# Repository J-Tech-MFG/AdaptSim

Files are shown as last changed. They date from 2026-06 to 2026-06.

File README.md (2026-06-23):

# AdaptSim

### A modular DIY direct drive sim racing ecosystem built from accessible parts, custom CAD, and open-source hardware.

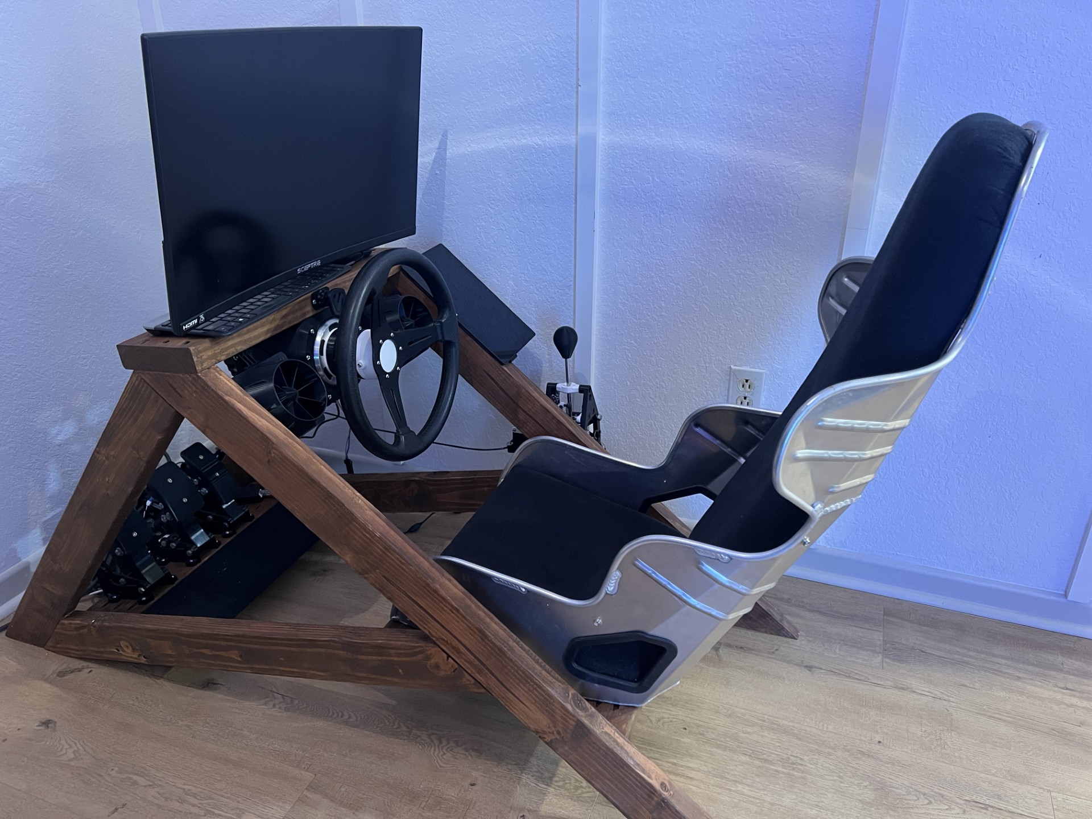
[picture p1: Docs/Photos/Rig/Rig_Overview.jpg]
Rig Overview


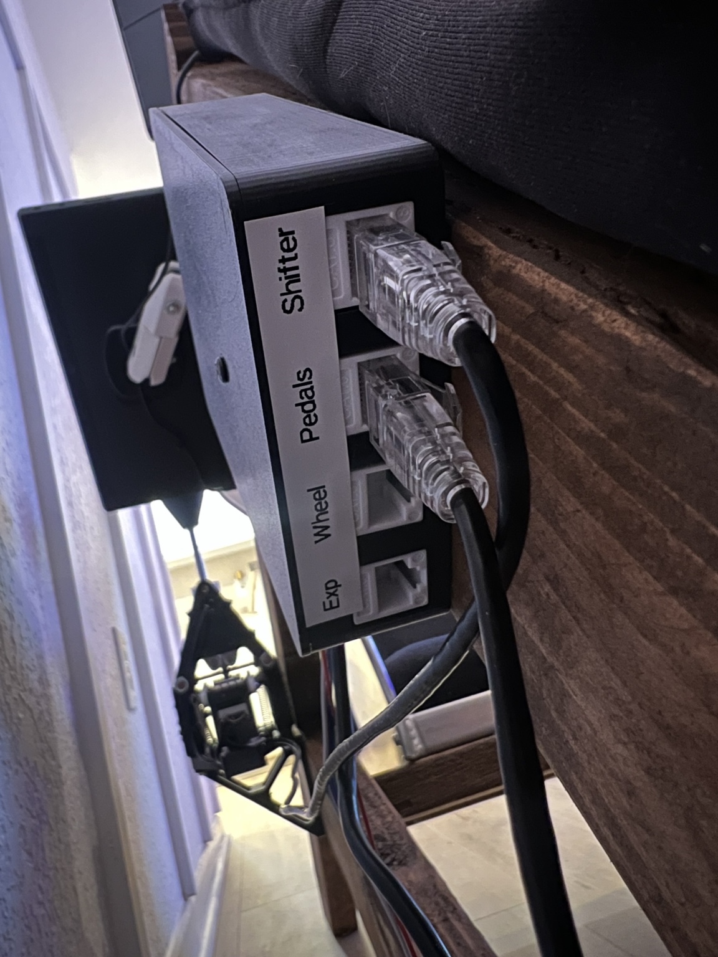
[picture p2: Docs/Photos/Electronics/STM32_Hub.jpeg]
RJ45 Controller








---

# Overview

AdaptSim is a DIY sim racing project centered around a custom STM32 controller, direct drive force feedback wheel, load-cell pedals, H-pattern shifter, pedal rumble system, and SimHub-powered wind simulation.

The goal of this project was simple:

> Build a high-performance simulator using affordable components, recycled hardware, 3D printed parts, and custom CAD rather than expensive proprietary equipment.

Everything was designed around adaptability. The included STEP files are intended to be modified and customized to fit whatever hardware you have available.

---

# Design Philosophy

AdaptSim is **not a kit**.

The parts used in this build were largely chosen based on what I already had available. Because of that, exact hardware counts and dimensions may differ from your build.

Instead of requiring exact replicas, the provided STEP files allow builders to:

- Modify dimensions
- Change mounting patterns
- Use different hardware
- Adapt electronics layouts
- Customize ergonomics

If you have different bearings, springs, fasteners, sensors, or materials, modify the CAD and make it your own.

---

# Features

## Direct Drive Wheel

- 350W Hoverboard Motor
- 36V Rated Motor
- 15 Pole Pair Configuration
- MT6701 Magnetic Encoder
- FFBeast Firmware
- STM32-based controller
- SimHub Compatible

## Load Cell Pedals

- Custom modified pedal design
- 200kg load cell brake
- HX711 load cell amplifier
- KY-035 analog hall sensors
- Magnetic throttle and clutch sensing
- Adjustable geometry
- Adjustable pedal spacing

## H-Pattern Shifter

- Fully custom CAD design
- Spring centering mechanism
- Limit switch gear detection
- Serviceable design

## Modular Electronics

- STM32F407VET6 controller
- RJ45 modular wiring system
- Dedicated wheel port
- Dedicated pedal port
- Dedicated shifter port
- Expansion port for future accessories

## SimHub Integration

- Dual pedal rumble motors
- Speed-based wind simulation
- Drafting effects
- Left/right airflow effects

---

# Rig Overview

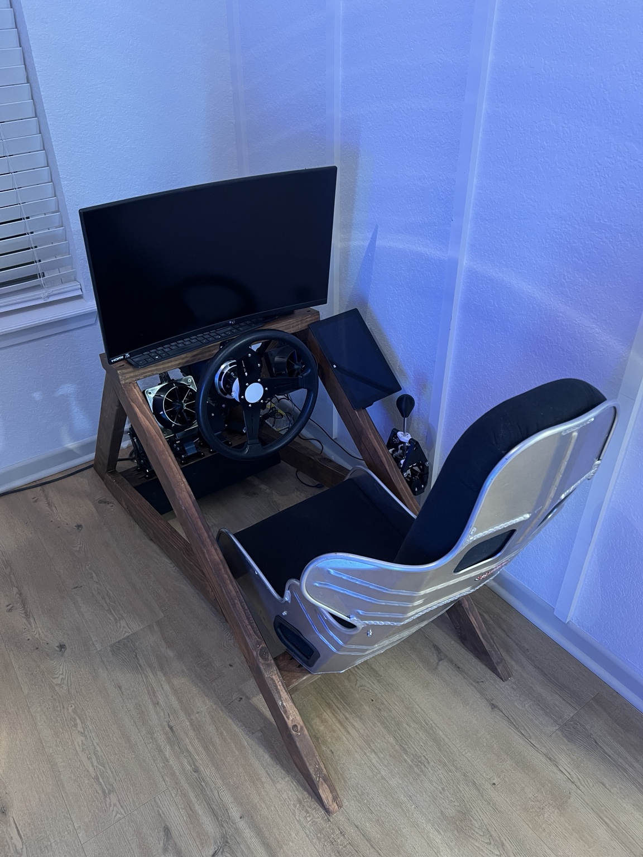
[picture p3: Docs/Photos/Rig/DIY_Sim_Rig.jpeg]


The simulator frame is a simple wood construction designed around affordability and rigidity.

Major systems include:

- Direct drive wheel
- Load-cell pedals
- H-pattern shifter
- SimHub wind simulator
- Pedal rumble feedback
- STM32 controller system

---

# Direct Drive Wheel

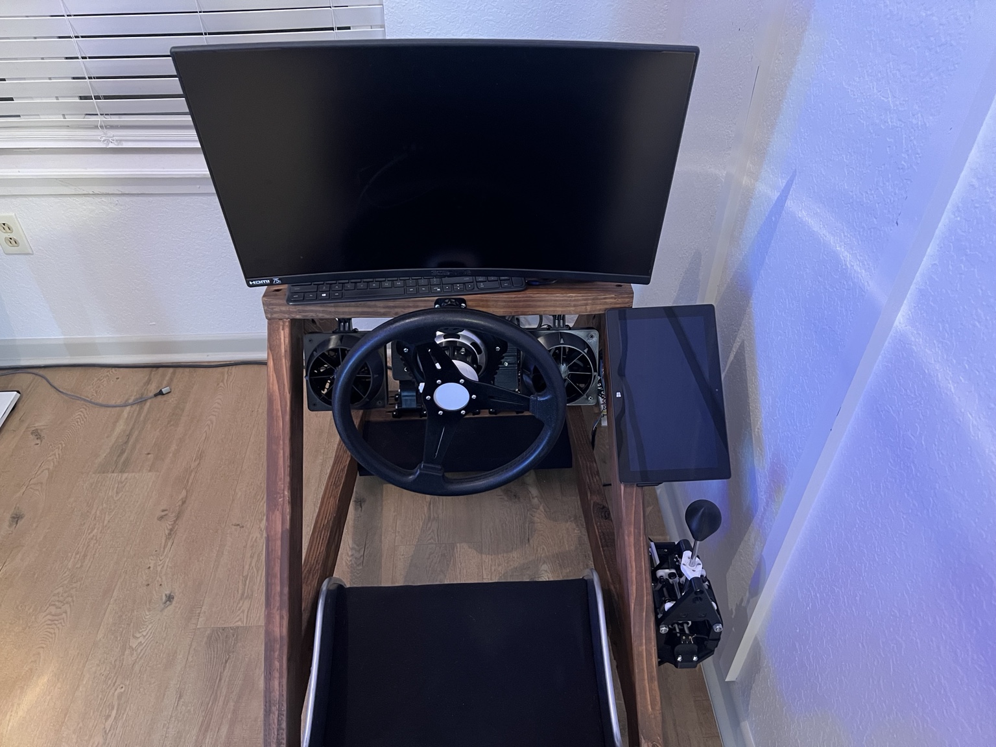
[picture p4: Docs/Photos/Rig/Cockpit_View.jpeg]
Wheel


## Hardware

| Component | Description |
|---|---|
| Motor | 6.5" Hoverboard Motor |
| Rated Power | 350W |
| Voltage | 36V |
| Pole Pairs | 15 |
| Encoder | MT6701 Magnetic Encoder |
| Controller | FFBeast |
| Power Supply | 24V 10A |

---

# Pedals

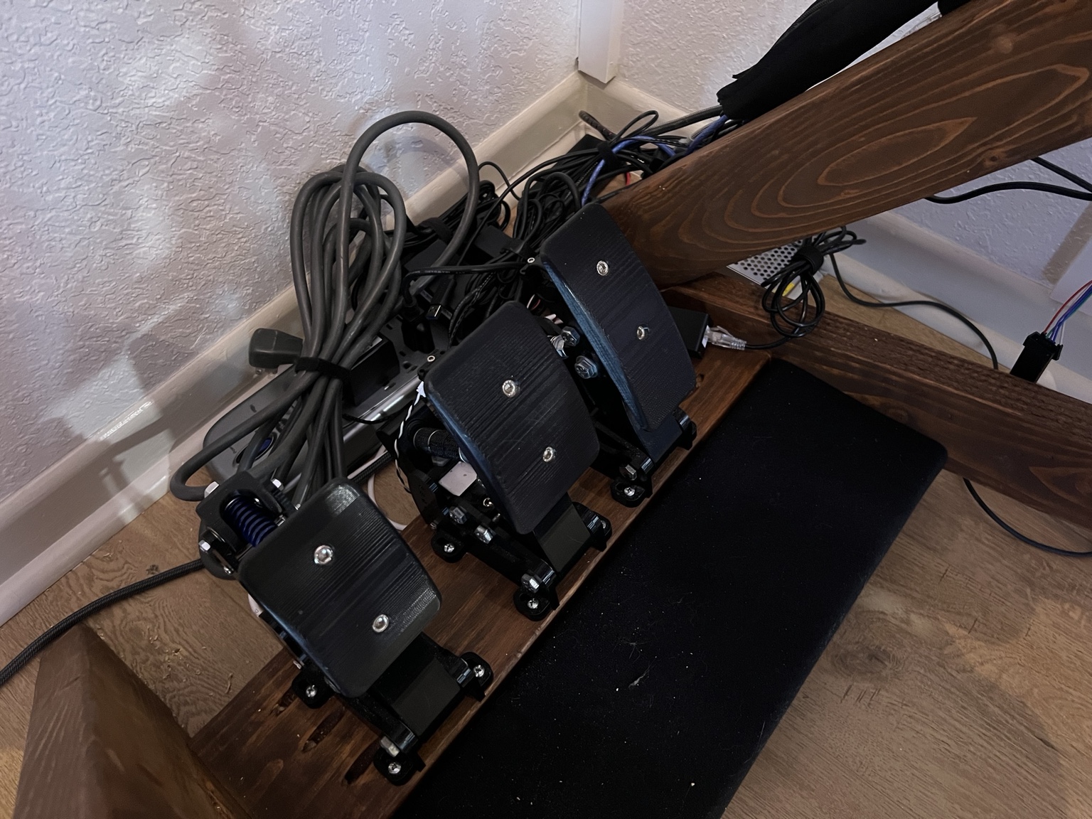
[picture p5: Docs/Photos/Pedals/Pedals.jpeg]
Pedals


## Sensors

### Throttle

- KY-035 Analog Hall Sensor
- 8mm x 3mm Neodymium Magnet

### Clutch

- KY-035 Analog Hall Sensor
- 8mm x 3mm Neodymium Magnet

### Brake

- 200kg Load Cell
- HX711 Amplifier Module

## Construction

- PETG Printed Components
- 608 Bearings
- M5 Threaded Rod
- M6 Hardware
- 5/16" Hardware

---

# H-Pattern Shifter

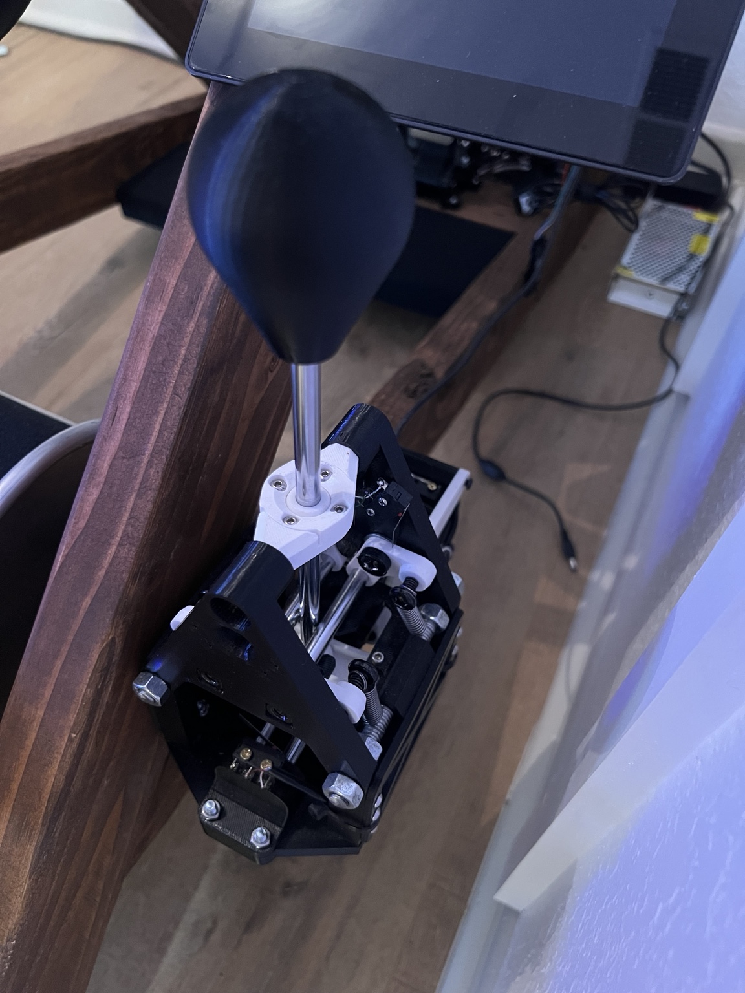
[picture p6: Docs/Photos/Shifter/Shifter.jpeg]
Shifter


The shifter was designed from scratch in CAD and developed around readily available hardware and linear motion components.

## Hardware

| Qty | Component |
|---|---|
| 4 | KW11-3Z-C Limit Switches |
| Assorted | 8mm Linear Rod |
| 4 | 8mm Linear Bearings |
| Assorted | M3 Hardware |
| Assorted | M4 Hardware |
| Assorted | M6 Threaded Rod |
| Assorted | M8 Threaded Rod |
| Assorted | 5/16" Threaded Rod |
| Assorted | Heat Set Inserts |
| Assorted | Extension Springs |

---

# Electronics Architecture

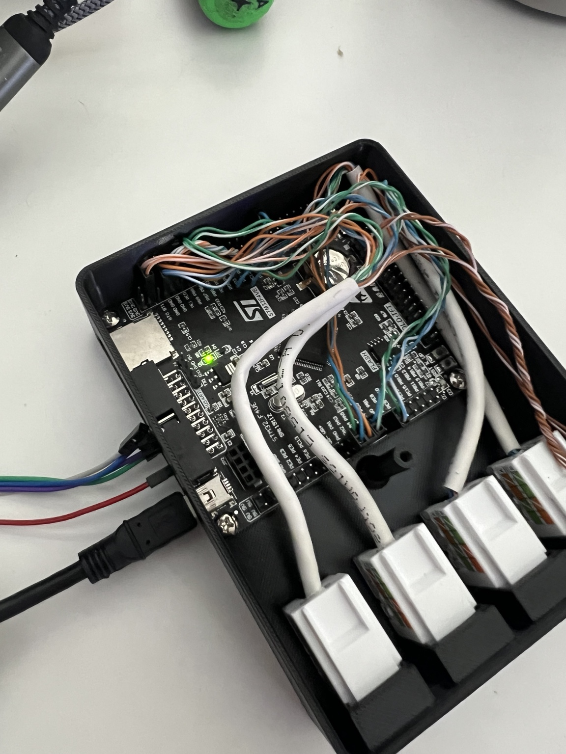
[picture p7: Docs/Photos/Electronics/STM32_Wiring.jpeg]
STM32 Wiring


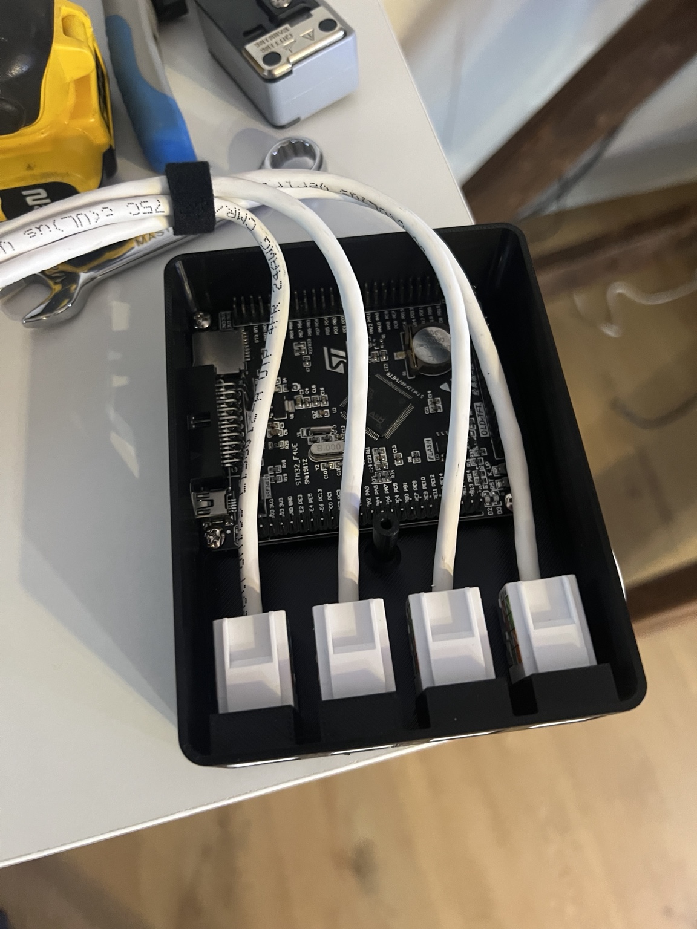
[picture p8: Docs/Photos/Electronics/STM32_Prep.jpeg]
STM32 Assembly


The entire simulator is built around a STM32F407VET6 microcontroller and a modular RJ45 wiring system.

## Ports

| Port | Function |
|---|---|
| Wheel | Wheel Controls |
| Pedals | Pedal Sensors |
| Shifter | Gear Detection |
| Expansion | Future Accessories |

Using RJ45 cabling allows easy serviceability and future expansion without rewiring the entire simulator.

---

# Pedal Rumble System

## Hardware

| Component | Description |
|---|---|
| Controller | Arduino Pro Micro |
| Driver | DRV8833 Dual H-Bridge |
| Motors | Xbox Controller Rumble Motors (2x) |
| Power Supply | 5V 2A USB Supply |

## SimHub Effects

- Wheel Slip
- ABS Feedback
- Wheel Lock
- Engine Vibration
- Road Impacts

---

# Wind Simulation

## Hardware

| Component | Description |
|---|---|
| Controller | Arduino Pro Micro |
| Fans | Thermalright TL-C12C PWM |
| Quantity | 2 |
| Voltage | 12V |
| Speed | 1550 RPM |
| Power Supply | 12V 1A |

## SimHub Effects

- Vehicle Speed
- Airflow Curving
- Drafting Effects

---

# CAD Files

The repository includes STEP files for:

- Pedals
- H-Pattern Shifter
- STM32 Controller Enclosure

Only STEP files are provided.

This allows builders to import and modify the designs in virtually any CAD software.

---

## Opening the Project

This repository intentionally omits some STM32CubeIDE workspace metadata files.

To open the project:

1. Open `AdaptSim_STM32.ioc` in STM32CubeMX
2. Generate code
3. Open the generated project in STM32CubeIDE
4. Build and flash

All required source code is included in this repository.

---

## SimHub Integration

This project includes optional SimHub-powered accessories:

- Pedal rumble feedback using Xbox controller rumble motors
- Wind simulation using dual PWM fans

Both systems use Arduino Pro Micro boards running firmware generated directly by SimHub.

No custom Arduino firmware is required.

See the Docs folder for setup instructions and wiring information.

---

# Credits

## Pedal Design Inspiration

This project began with the excellent pedal design by:

https://www.printables.com/model/1394243-sim-racing-pedals-with-load-cell-v2

The pedal assemblies in this repository are heavily modified versions adapted to fit this simulator's specific requirements.

---

## Shifter Inspiration

The shifter was inspired by:

https://dazprojects.com/products/h-shifter-3d-models

No files, models, or CAD data were purchased, downloaded, or reused. The design included here was created independently from scratch.

---

## Wind Simulator Credits

The wind simulator used in this project is based on the excellent design created by:

https://makerworld.com/en/models/1561872-3d-printed-wind-simulator-kit-for-sim-racing

I used their printed fan mounts and wind simulation design directly in my build because it is a well-designed and easy-to-implement solution.

The only significant modification was the electronics enclosure and controller implementation. Instead of the original Arduino Uno based design, this project uses an Arduino Pro Micro integrated into the overall AdaptSim electronics ecosystem.

The original creator's files are not included in this repository. If you would like to build the wind simulator, please visit their MakerWorld page and download the files directly from the original source.

Thank you to the original designer for making the project available to the community.

---

# License

This project is released under the MIT License.

Build it. Modify it. Improve it. Share it.

🏁

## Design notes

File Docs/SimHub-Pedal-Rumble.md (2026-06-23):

# Pedal Rumble System

## Hardware

- Arduino Pro Micro
- DRV8833 Dual H-Bridge Driver
- 2x Xbox Controller Rumble Motors
- 5V 2A USB Power Supply

## SimHub Configuration

Device Type:
- Dual Motor Output

Outputs:
- Motor 1 = Brake
- Motor 2 = Throttle

## Notes

Firmware is generated and uploaded directly by SimHub.
No custom Arduino code is required.

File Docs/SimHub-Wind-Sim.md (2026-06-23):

# Wind Simulation System

## Hardware

- Arduino Pro Micro
- 2x Thermalright TL-C12C PWM Fans
- 12V 1A Power Supply

## SimHub Configuration

Device Type:
- PWM Fan Controller

Pins:
- Fan 1 PWM = D9
- Fan 2 PWM = D10

## Features

- Speed-based airflow
- Left/right airflow effects
- Drafting effects

## Credits

Fan mounting concept based on:

https://makerworld.com/en/models/1561872-3d-printed-wind-simulator-kit-for-sim-racing

The original fan files are not included in this repository.

## Notes

Firmware is generated and uploaded directly by SimHub.
No custom Arduino code is required.

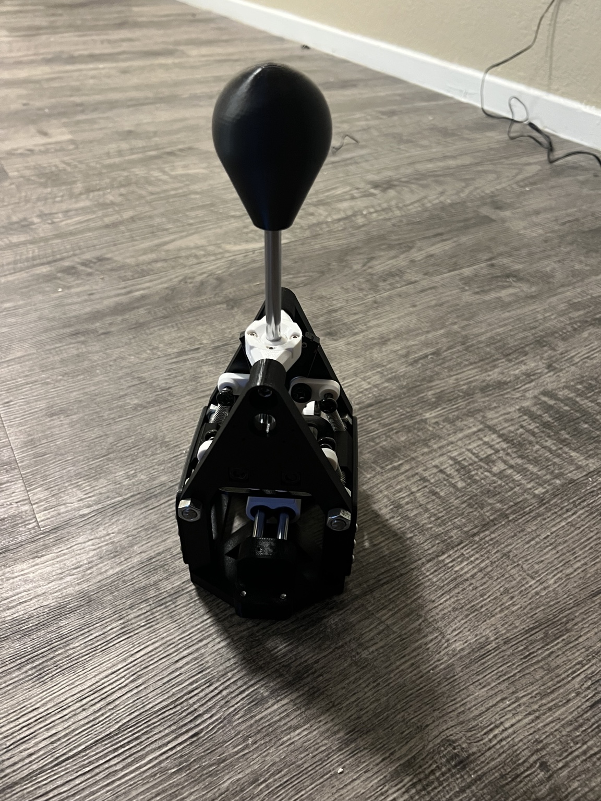
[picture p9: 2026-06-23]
Docs/Photos/Shifter/Shifter_Rear_View.jpeg

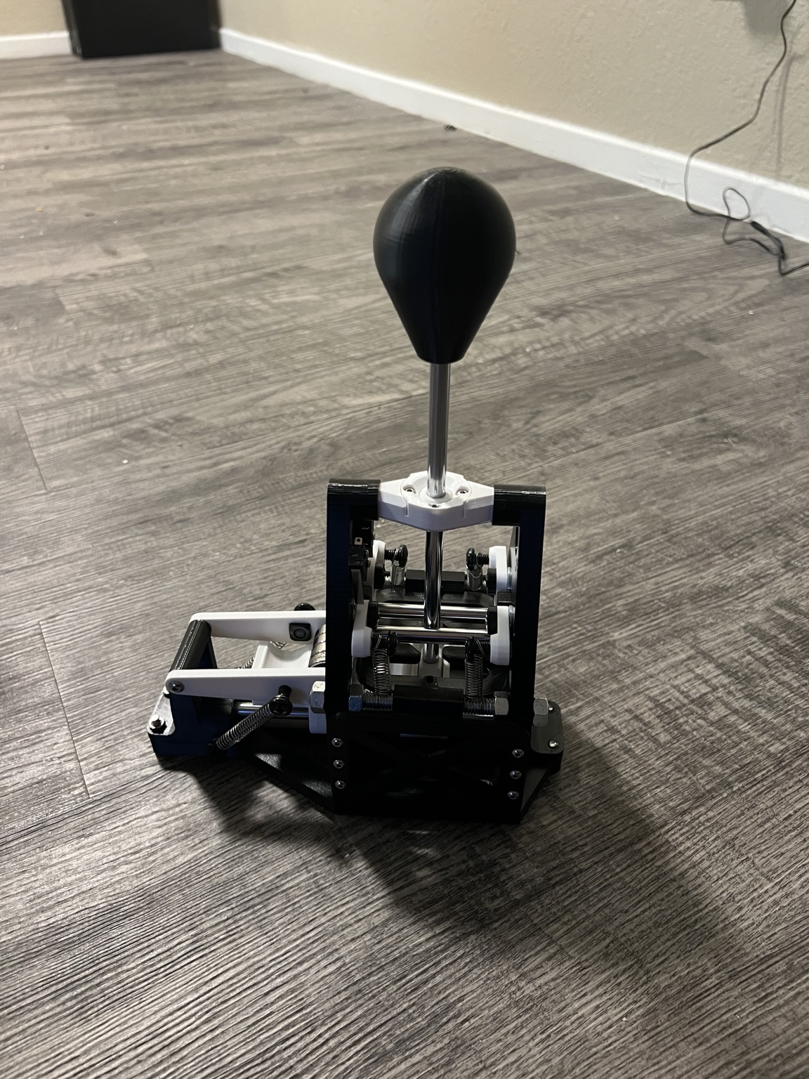
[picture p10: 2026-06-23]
Docs/Photos/Shifter/Shifter_Side_View.jpeg

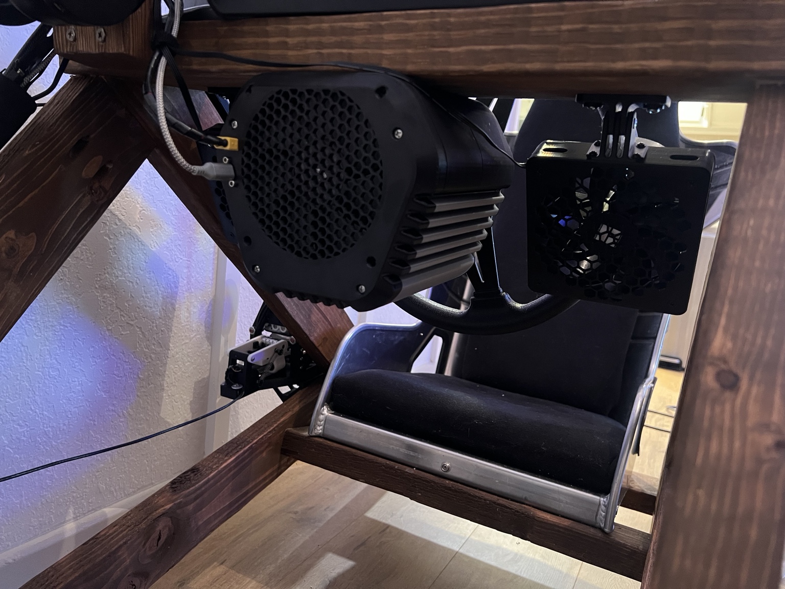
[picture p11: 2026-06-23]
Docs/Photos/Wheel/Wheel_and_Wind.jpeg

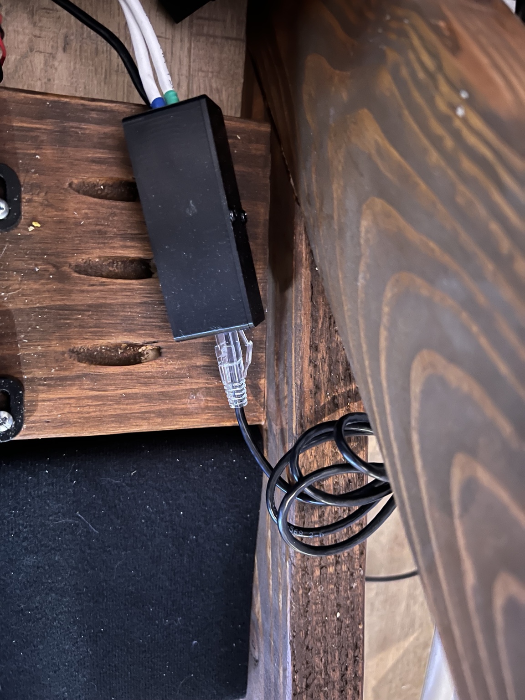
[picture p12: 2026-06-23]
Docs/Photos/Pedals/Pedal_Module.jpeg

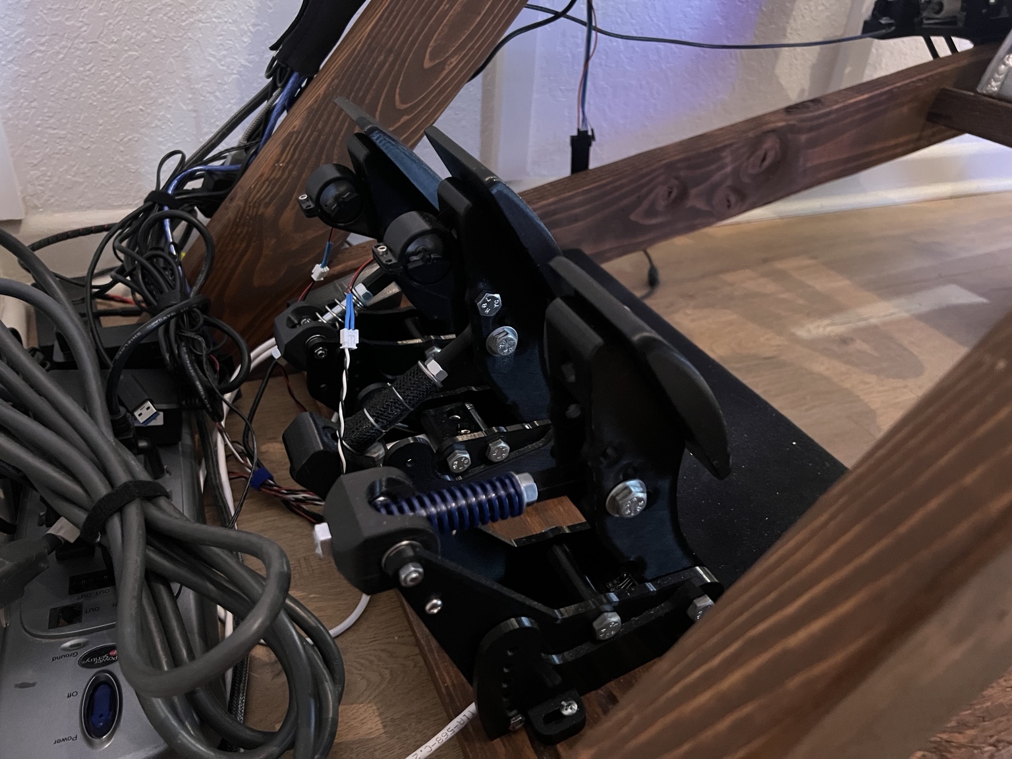
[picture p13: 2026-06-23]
Docs/Photos/Pedals/Pedals_Side_View.jpeg

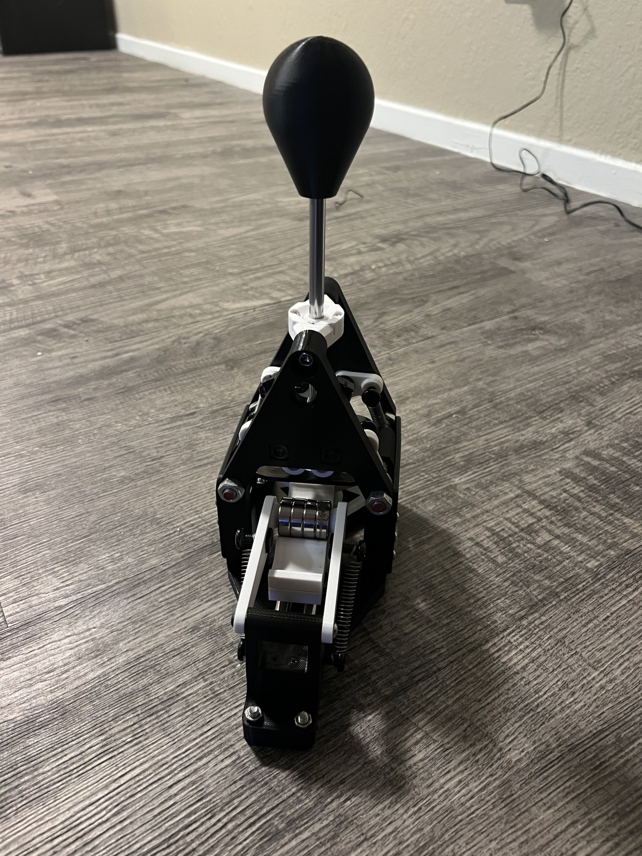
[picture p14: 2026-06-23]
Docs/Photos/Shifter/Shifter_Front_View.jpeg

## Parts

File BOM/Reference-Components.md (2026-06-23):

# Reference Components

Work in progress.

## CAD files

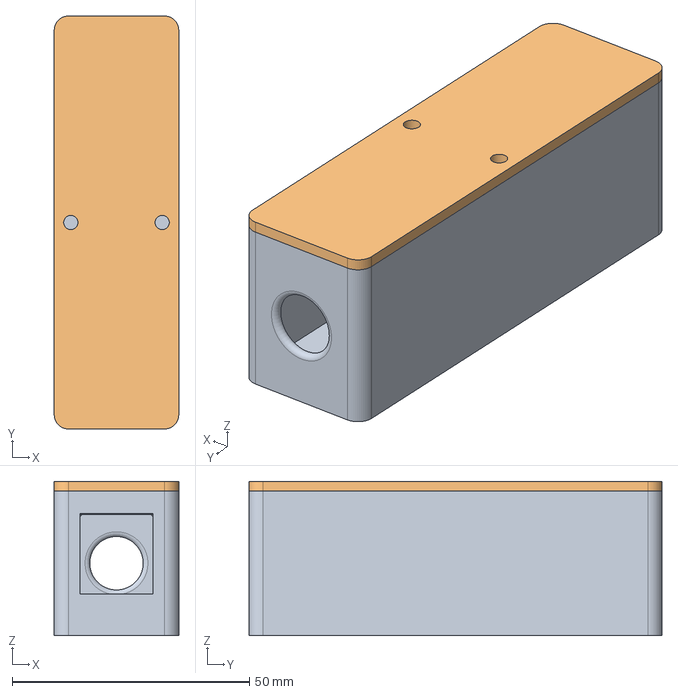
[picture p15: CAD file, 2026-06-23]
CAD/Pedals/Sim_Pedal_Electronic_Enclosure.step
26.3 x 87.0 x 32.5 mm

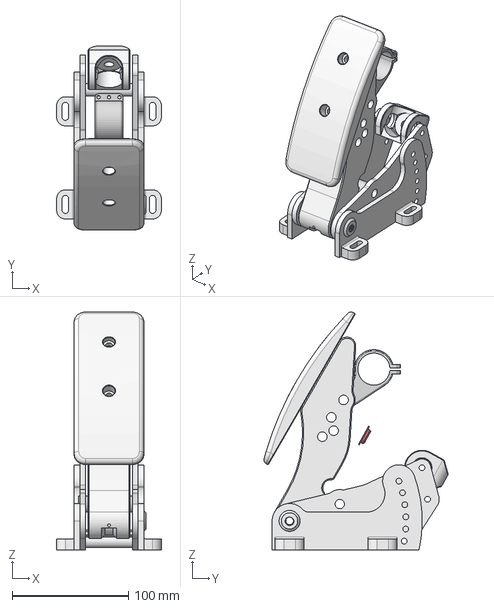
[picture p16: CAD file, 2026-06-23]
CAD/Pedals/FreeSim-Pedal-Throttle.step
90.0 x 158.3 x 204.5 mm
Pedal_Arm

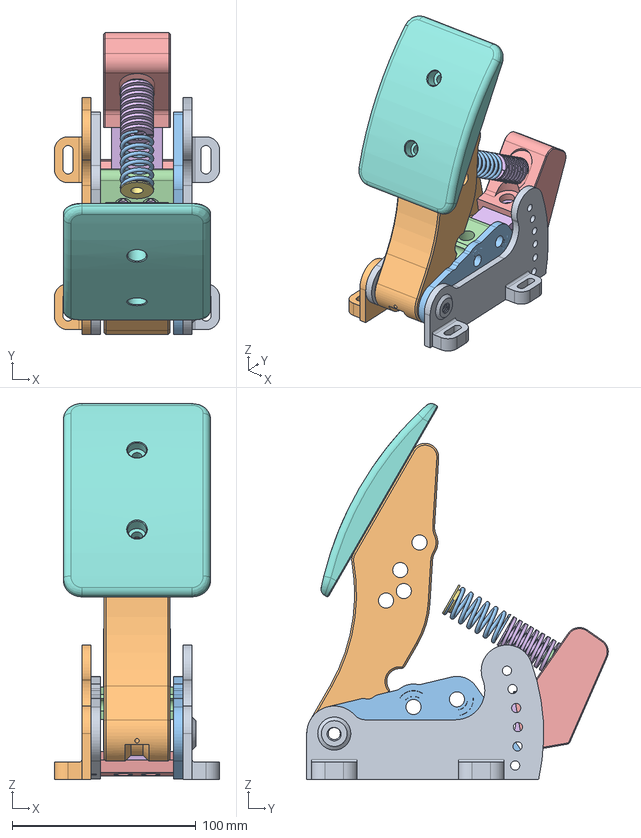
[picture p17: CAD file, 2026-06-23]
CAD/Pedals/FreeSim-Pedal-Brake.step
90.0 x 164.1 x 204.6 mm
Side_Mount_Left
Pedal_Arm (1)

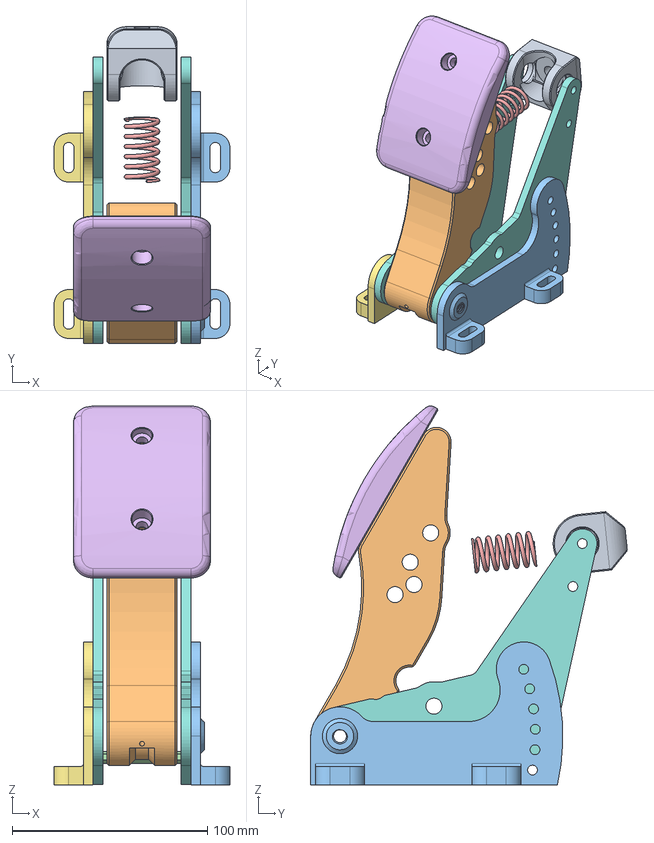
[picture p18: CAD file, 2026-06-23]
CAD/Pedals/FreeSim-Pedal-Clutch.step
90.0 x 162.0 x 193.9 mm
Pedal_Arm (2)
Side_Mount_Left
KY-035_Analog_Hall_Mount

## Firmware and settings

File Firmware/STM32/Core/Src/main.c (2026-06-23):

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
/* Includes ------------------------------------------------------------------*/
#include "main.h"
#include "usb_device.h"

/* USER CODE BEGIN Includes */
#include <stdio.h>
#include <string.h>
#include "usbd_hid.h"
/* USER CODE END Includes */

ADC_HandleTypeDef hadc1;

void SystemClock_Config(void);
static void MX_GPIO_Init(void);
static void MX_ADC1_Init(void);
/* USER CODE BEGIN 0 */
extern USBD_HandleTypeDef hUsbDeviceFS;

typedef struct __attribute__((packed))
{
  uint16_t throttle;
  uint16_t brake;
  uint16_t clutch;
  uint32_t buttons;
} SimHID_Report_t;

#define THROTTLE_MIN 2190
#define THROTTLE_MAX 3150

#define CLUTCH_MIN   2180
#define CLUTCH_MAX   1494

#define BRAKE_MIN    22000
#define BRAKE_MAX    600000

static int32_t clamp_i32(int32_t value, int32_t min, int32_t max)
{
  if (value < min) return min;
  if (value > max) return max;
  return value;
}

static uint32_t read_adc_channel(uint32_t channel)
{
  ADC_ChannelConfTypeDef sConfig = {0};

  sConfig.Channel = channel;
  sConfig.Rank = 1;
  sConfig.SamplingTime = ADC_SAMPLETIME_15CYCLES;

  HAL_ADC_ConfigChannel(&hadc1, &sConfig);
  HAL_ADC_Start(&hadc1);
  HAL_ADC_PollForConversion(&hadc1, 10);
  uint32_t value = HAL_ADC_GetValue(&hadc1);
  HAL_ADC_Stop(&hadc1);

  return value;
}

static void hx711_delay(void)
{
  for (volatile int i = 0; i < 80; i++);
}

static int32_t hx711_read(void)
{
  int timeout = 1000000;

  while (HAL_GPIO_ReadPin(GPIOB, GPIO_PIN_0) == GPIO_PIN_SET)
  {
    if (--timeout == 0)
      return 0;
  }

  int32_t count = 0;

  for (uint8_t i = 0; i < 24; i++)
  {
    HAL_GPIO_WritePin(GPIOB, GPIO_PIN_1, GPIO_PIN_SET);
    hx711_delay();

    count <<= 1;
    if (HAL_GPIO_ReadPin(GPIOB, GPIO_PIN_0) == GPIO_PIN_SET)
      count++;

    HAL_GPIO_WritePin(GPIOB, GPIO_PIN_1, GPIO_PIN_RESET);
    hx711_delay();
  }

  // Gain 128, Channel A
  HAL_GPIO_WritePin(GPIOB, GPIO_PIN_1, GPIO_PIN_SET);
  hx711_delay();

  HAL_GPIO_WritePin(GPIOB, GPIO_PIN_1, GPIO_PIN_RESET);
  hx711_delay();

  if (count & 0x800000)
    count |= 0xFF000000;

  return count;
}

/* USER CODE END 0 */

/**
  * @brief  The application entry point.
  * @retval int
  */
int main(void)
{

  /* MCU Configuration--------------------------------------------------------*/

  /* Reset of all peripherals, Initializes the Flash interface and the Systick. */
  HAL_Init();

  /* Configure the system clock */
  SystemClock_Config();

  /* Initialize all configured peripherals */
  MX_GPIO_Init();
  MX_USB_DEVICE_Init();
  MX_ADC1_Init();
  /* Infinite loop */
  /* USER CODE BEGIN WHILE */
  while (1)
  {
    /* USER CODE END WHILE */

    /* USER CODE BEGIN 3 */

	  uint32_t clutchRaw   = read_adc_channel(ADC_CHANNEL_4);
	  uint32_t throttleRaw = read_adc_channel(ADC_CHANNEL_5);
	  static int32_t brakeRaw = BRAKE_MIN;
	  static uint32_t lastBrakeRead = 0;

	  if (HAL_GetTick() - lastBrakeRead >= 80)
	  {
	    int32_t newBrakeRaw = hx711_read();

	    if (newBrakeRaw != 0)
	    {
	      brakeRaw = newBrakeRaw;
	    }

	    lastBrakeRead = HAL_GetTick();
	  }

	  uint16_t throttleAxis =
	      (uint16_t)clamp_i32(
	          ((int32_t)throttleRaw - THROTTLE_MIN) * 32767 /
	          (THROTTLE_MAX - THROTTLE_MIN),
	          0, 32767);

	  uint16_t clutchAxis =
	      (uint16_t)clamp_i32(
	          (CLUTCH_MIN - (int32_t)clutchRaw) * 32767 /
	          (CLUTCH_MIN - CLUTCH_MAX),
	          0, 32767);

	  static int32_t brakeFiltered = BRAKE_MIN;

	  brakeFiltered = (brakeFiltered * 7 + brakeRaw) / 8;

	  uint16_t brakeAxis =
	      (uint16_t)clamp_i32(
	          (int32_t)(((int64_t)brakeFiltered - BRAKE_MIN) * 32767 /
	          (BRAKE_MAX - BRAKE_MIN)),
	          0, 32767);

	  if (brakeAxis < 500)
	      brakeAxis = 0;

	  uint8_t left  = HAL_GPIO_ReadPin(GPIOA, GPIO_PIN_0) == GPIO_PIN_RESET;
	  uint8_t right = HAL_GPIO_ReadPin(GPIOA, GPIO_PIN_1) == GPIO_PIN_RESET;
	  uint8_t fore  = HAL_GPIO_ReadPin(GPIOA, GPIO_PIN_2) == GPIO_PIN_RESET;
	  uint8_t aft   = HAL_GPIO_ReadPin(GPIOA, GPIO_PIN_3) == GPIO_PIN_RESET;

	  uint32_t buttons = 0;

	  if (right && aft)           buttons |= (1UL << 0);  // Gear 1
	  else if (right && fore)     buttons |= (1UL << 1);  // Gear 2
	  else if (!left && !right && aft)  buttons |= (1UL << 2);  // Gear 3
	  else if (!left && !right && fore) buttons |= (1UL << 3);  // Gear 4
	  else if (left && aft)       buttons |= (1UL << 4);  // Gear 5
	  else if (left && fore)      buttons |= (1UL << 5);  // Gear 6

	  SimHID_Report_t report;

	  report.throttle = throttleAxis;
	  report.brake = brakeAxis;
	  report.clutch   = clutchAxis;
	  report.buttons  = buttons;

	  USBD_HID_SendReport(&hUsbDeviceFS, (uint8_t *)&report, sizeof(report));

	  HAL_Delay(10);
  }
  /* USER CODE END 3 */
}

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


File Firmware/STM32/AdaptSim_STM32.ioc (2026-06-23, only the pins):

Mcu.UserName=STM32F407VETx
PA0-WKUP.Signal=GPIO_Input
PA1.Signal=GPIO_Input
PA11.Signal=USB_OTG_FS_DM
PA12.Signal=USB_OTG_FS_DP
PA13.Signal=SYS_JTMS-SWDIO
PA14.Signal=SYS_JTCK-SWCLK
PA2.Signal=GPIO_Input
PA3.Signal=GPIO_Input
PA4.Signal=ADCx_IN4
PA5.Signal=ADCx_IN5
PB0.Signal=GPIO_Input
PB1.Signal=GPIO_Output
PH0-OSC_IN.Signal=RCC_OSC_IN
PH1-OSC_OUT.Signal=RCC_OSC_OUT
